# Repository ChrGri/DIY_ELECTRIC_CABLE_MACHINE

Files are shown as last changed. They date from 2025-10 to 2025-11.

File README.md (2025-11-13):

# ESP32-Powered DIY Smart Cable Machine

An open-source, smart digital resistance machine using an ESP32, a high-torque StepperOnline A6 servo, and 3D-printed components. 

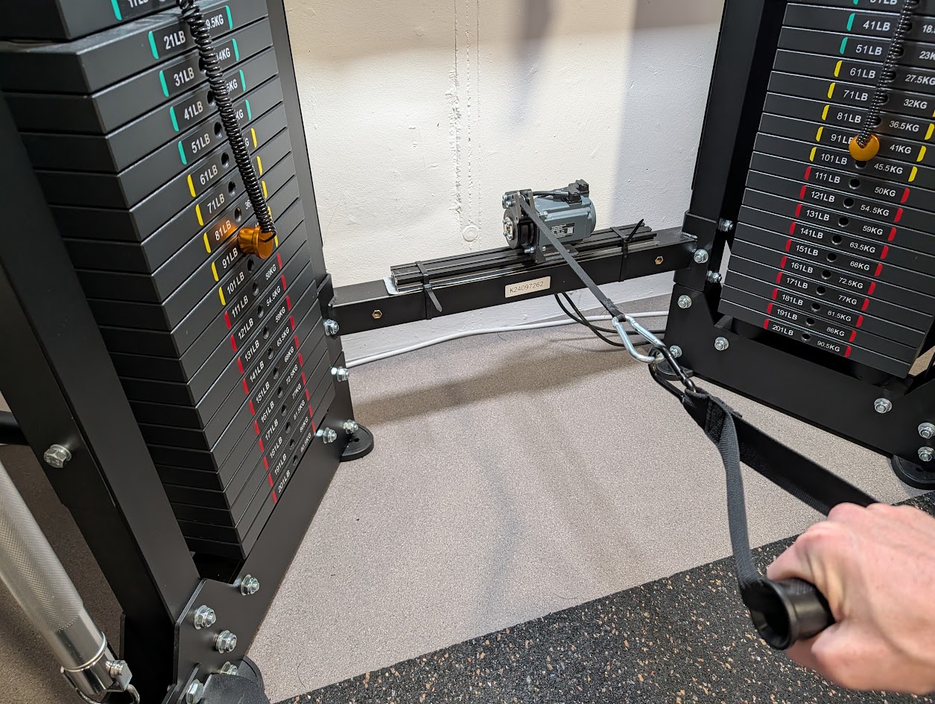
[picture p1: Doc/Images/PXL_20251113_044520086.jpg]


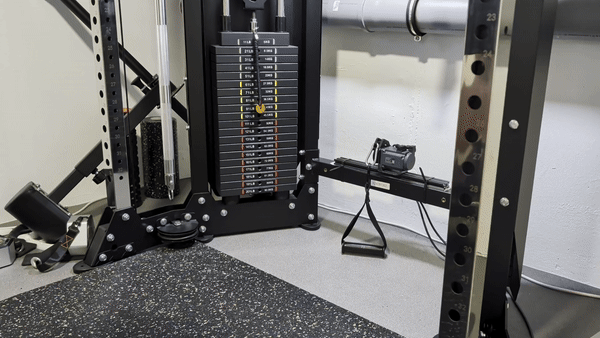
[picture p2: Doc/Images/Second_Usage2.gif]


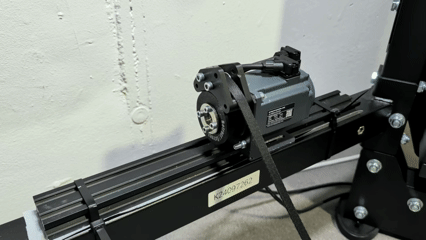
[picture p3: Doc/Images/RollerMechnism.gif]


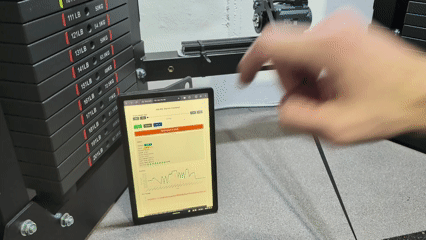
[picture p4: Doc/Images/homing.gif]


Action video, see [here](Doc/Videos/ActionVideo_1.mp4) and [here](Doc/Videos/ActionVideo_2.mp4).

The machine can be parameterized via web interface see <br>


# 🏋️ About The Project

This project is a Do-It-Yourself (DIY) approach to modern smart gyms. Instead of using a traditional weight stack, this machine uses a powerful closed-loop servo motor (StepperOnline A6) controlled by an ESP32 to provide resistance. This allows for digitally adjustable weight, smooth operation, and the potential for advanced features like eccentric-only training, custom resistance curves, and workout tracking.

The core of the build relies on accessible components: the powerful ESP32, a reliable industrial servo, a standard gym cable/handle, and custom 3D-printed parts for the spool and mounting. The ESP32 S3 was selected, since it has onboard WiFi and Bluetooth functionality and sufficient compute to allow web based control.  

## ✨ Key Features

- Digitally Adjustable Resistance: Change your "weight" from a web interface or physical buttons.
- High-Torque Servo: The StepperOnline A6 servo provides strong, smooth, and precise resistance.
- ESP32 Controller: Wi-Fi and Bluetooth-ready for a new UI, mobile app control, and OTA (Over-The-Air) updates.
- Fully Open-Source: All 3D models (STL/STEP) and firmware code are provided.
- Cost-Effective: Built for a fraction of the cost of commercial smart gyms.
- Customizable: Modify the code to add new modes (eccentric, isometric, chains) or integrate with other fitness apps.
- controller via web interface --> <br>
 <br>
- maximum force 12kg with the small A6 1.27Nm servo in direct drive, so no gearing. The larger 3.18 Nm might be able to provide 30 kg. 

# Support the team
I :heart: doing research. New hardware (e.g. servos, periphery, PCBs) is very expensive. Feel free to support me and thus fasten up the research activity.

Dev | captainchris |
--- | --- |
Buy me a coffee |  | 
Ko-fi |  |

## 🛠️ Bill of Materials (BOM)

Core Components
| Component | Model / Spec | Notes | (affiliate) link|
|--|--|--|--|
| Microcontroller | ESP32 S3 dev board |  | [Amazon](https://amzn.to/48NTnuW) |
| RJ45  cable |  | | [Amazon](https://amzn.to/47rE3Si) |
| TTL to Modbus converter |  |  | [Amazon](https://amzn.to/4nr72vo) |
| Servo Motor | StepperOnline A6 Servo | | [A6 1,27Nm](https://www.omc-stepperonline.com/de/a6-serie-400w-rs485-ac-servomotor-kit-3000rpm-1-27nm-17-bit-absolutwertgeber-ip67-a6-rs400h2a1-m17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) or [A6 3,18Nm](https://www.omc-stepperonline.com/de/a6-serie-1000w-rs485-ac-servomotor-kit-3000rpm-3-18nm-17-bit-absolutwertgeber-ip67-a6-rs1000h2a1-m17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)|
| Gym Cable | 3mm Polyster cord x 30m | Polyster cord is strong. | [Polyster cord](https://amzn.to/49fXEY2) |
| Handle | Standard D-Handle | Any cable machine attachment works. |  |

### Custom PCB
In the making.

### 3D Printed Parts

- Main Spool (attaches to servo shaft)
- Motor Mount
- ESP32 Enclosure

(All .stl and .step files are available in the /3D-Models directory of this repository)

## 🔌 Wiring Diagram

Here is the basic wiring schematic for connecting the ESP32 to the servo driver.

Warning: You are working with high-voltage AC (for the PSU) and high-current DC (for the servo). Always double-check your connections and ensure everything is unplugged when wiring.

### Connect the ESP32 to the TTL-to-Modbus board
   
| from ESP32 <br>  | TTL-to-Modbus Adapter <br>  |
|--|--|
| 3V3 | VCC |
| GPIO 4 (TX) | TXD |
| GPIO 6 (RX)  | RXD | 
| GND | GND |

### Connect the TTL-to-Modbus board to the RJ45 plug
| TTL-RJ45 Adapter <br>  | RJ45 <br>  |
|--|--|
| A+  | Pin 4 | 
| B- | Pin 5 |
| GND | Pin 8 |

 <br>
For Modbus communication and wiring please refer to this https://help.stepperonline.com/en/article/a6-servo-motor-rs485-operation-instruction-1u47bbl/

In the end, the wiring should look like this <br>
.

### Connect the RJ45 plug into the A6 servos CN3 port. 
Connect the RJ45 plug to CN3 port of the servo, port (5) in the image below:<br> 


### AC and Servo wiring
Please refer to the A6 manual for wiring of the A6 servo. As an example, here is how mine is wired up: <br>


## 💾 Firmware Setup

The firmware is written using the Arduino framework for the ESP32.
### VSCode
Install [VSCode](https://code.visualstudio.com/)

### PlatformIO
Install [PlatformIO](https://platformio.org/install/ide?install=vscode) in Visual Studio Code

> ![Note]
> When you restart VS Code for the first time after the PlatformIO extension is installed, it will install and build the development environment which will take a moment. Wait until it is complete before attempting to open the project.

### Flashing the firmware

1. IDE: Open [Code/Esp32S3](https://github.com/ChrGri/DIY_ELECTRIC_CABLE_MACHINE/tree/main/Code/Esp32S3) folder in VSCode
2. Flash: Build and upload the firmware to your ESP32.

## 🚀 How to Use

1. Power On: Connect the power supply and turn on the system.
2. Connect: The ESP32 will create a Wi-Fi network (or join yours, based on your config). Connect to its IP address from your phone or computer.
3. Web Interface: You will see a simple web page.
4. Set Weight: Enter your desired resistance (in kg or lbs) and press "Set".
5. Work Out! The servo will engage and provide resistance as you pull the handle.

## 📈 To-Do / Future Plans

[ ] Read servo alarms

[ ] Add eccentric resistance mode (higher resistance on release).

[ ] Workout tracking and history.

[ ] Add physical buttons/encoder to set weight without a phone.

## 🤝 Contributing

Pull requests are welcome! If you have ideas for improvements, new features, or bug fixes, please open an issue first to discuss what you would like to change.

1. Fork the Project
2. Create your Feature Branch (git checkout -b feature/AmazingFeature)
3. Commit your Changes (git commit -m 'Add some AmazingFeature')
4. Push to the Branch (git push origin feature/AmazingFeature)
5. Open a Pull Request

## ⚠️ Safety Disclaimer ⚠️

Build and use this device at your own risk.

This is an advanced DIY project that involves:

- High-Voltage AC: You will be working with mains AC voltage for the power supply, which carries a risk of severe electric shock or death.
- Powerful Motor: The A6 servo motor is extremely powerful. It can cause serious injury if hands, hair, or clothing get caught in the spool or cable.
- High Tension: The machine operates under high tension. Failure of 3D-printed parts, the cable, or mountings can result in a sudden release of load, posing a significant risk of injury.

The author(s) and contributors to this project assume no responsibility or liability for any injuries, damages, or losses resulting from the construction or use of this device. You are solely responsible for ensuring the safety of your build, performing all necessary safety checks, and using the machine in a safe manner.

## 📄 License
This project is licensed under the Creative Commons Attribution-NonCommercial-ShareAlike 4.0 International (CC BY-NC-SA 4.0). See the LICENSE file for details.

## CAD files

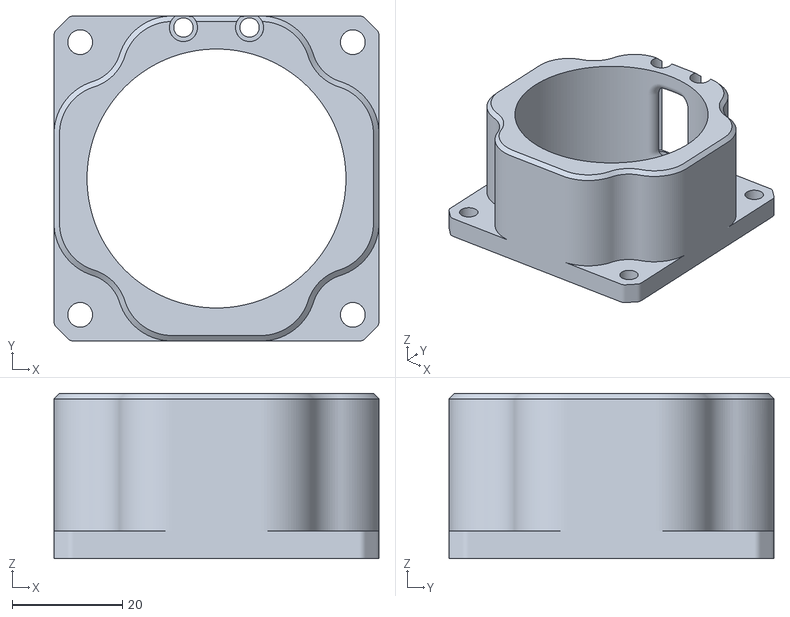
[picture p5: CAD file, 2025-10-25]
Cad/Stl/Housing.stl
59.0 x 59.0 x 30.0

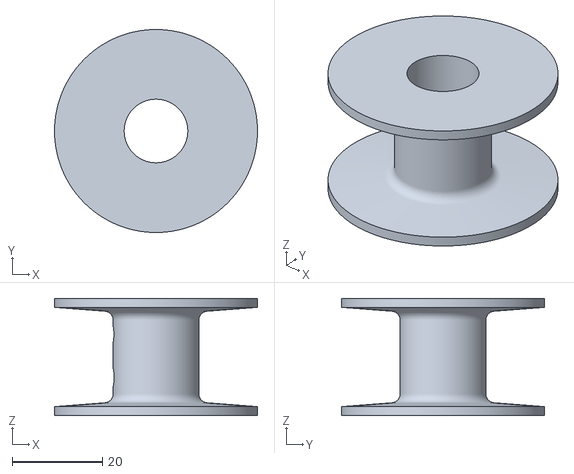
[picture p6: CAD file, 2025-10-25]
Cad/Stl/Roller.stl
45.0 x 45.0 x 26.0

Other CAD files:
Cad/F3d/A6ServoResistanceMachine v8.f3d

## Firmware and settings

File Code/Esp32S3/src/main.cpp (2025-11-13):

/*
 * Modbus Servo Control via Web Interface - ESP32-S3
 *
 * Implements a simple WiFi Manager, Modbus control, WebSocket interface,
 * and sends log messages/status data to the web browser via WebSocket.
 * Includes three live charts (Position/Time, Voltage/Time, Speed/Time) using Chart.js.
 *
 * *** MODIFIED ***
 * - Changed slider to represent and control Target Weight (kg) instead of Max Torque (%).
 * - Calculated conversion factor based on provided servo specs.
 * - Added third chart for Speed (rpm).
 */

#include <WiFi.h>
#include "esp_wifi.h"
#include <ESPAsyncWebServer.h>
#include <AsyncTCP.h>
#include <ModbusMaster.h>
#include <HardwareSerial.h>
#include <ArduinoJson.h>
#include <Preferences.h>

// --- Pin Definitions (ESP32-S3) ---
#define RXD2_PIN 6 // Modbus Serial2 RX
#define TXD2_PIN 4 // Modbus Serial2 TX

// --- WiFi Configuration ---
Preferences preferences;
String savedSSID = "";
String savedPassword = "";
const char *apSSID = "ServoSetup";

// --- Modbus Configuration ---
#define SERVO_DRIVE_SLAVE_ID 1
ModbusMaster node;
HardwareSerial ModbusSerial(2);

// --- Modbus Register Addresses (Hex) ---
#define REG_CONTROL_MODE 0x0000        // C00.00
#define REG_TARGET_SPEED 0x0321        // C03.21
#define REG_TORQUE_REF_SRC 0x0340      // C03.40
#define REG_TARGET_TORQUE 0x0341       // C03.41
#define REG_MODBUS_SERVO_ON 0x0411     // Servo Enable/Disable (Write)
#define REG_DI5_FUNCTION 0x0410        // C04.10
#define REG_SOFT_LIMIT_ENABLE 0x0607   // C06.07 (1=Enable +/- Limits)
#define REG_SOFT_LIMIT_NEG 0x0608      // C06.08 (32-bit Negative Limit) - Alias for clarity
#define REG_C06_08 REG_SOFT_LIMIT_NEG  // Keep old name for compatibility
#define REG_OUT_OF_CONTROL_PROT 0x0620 // C06.20 (Out of Control Protection Mode)
#define REG_SPEED_FEEDBACK 0x4001      // U40.01
#define REG_TORQUE_FEEDBACK 0x4003     // U40.03
#define REG_DI_STATUS 0x04004          // C040.04
#define REG_BUS_VOLTAGE 0x4006         // U40.06
#define REG_RMS_CURRENT 0x400C         // U40.0C
#define REG_POSITION_FEEDBACK_L 0x4016 // U40.16 (Low)
#define REG_POSITION_FEEDBACK_H 0x4017 // U40.16 (High)
#define REG_TEMP_IGBT 0x4030           // U40.30 (IGBT Temperature in 0.1 C)
#define REG_TEMP_MOTOR 0x4031          // U40.31 (Motor Temperature in 0.1 C)
#define REG_SERVO_STATUS 0x410A        // U41.0A

// --- Webserver & WebSocket ---
AsyncWebServer server(80);
AsyncWebSocket ws("/ws");
StaticJsonDocument<350> wsJsonTx; // Slightly increased size for temp values
StaticJsonDocument<128> wsJsonRx;
#define MAX_LOG_MSG_LENGTH 150

// --- Global State Variables ---
bool servoIsEnabledTarget = false;
bool servoIsEnabledActual = false;
bool modbusOk = false;
int16_t currentTargetTorque = 0; // Represents the MAX torque (0-2000) sent to servo
int16_t actualSpeed = 0;
int16_t actualTorque = 0;
uint16_t busVoltage = 0;
int16_t rmsCurrent = 0;
int32_t actualPosition = 0;
int16_t igbtTemp = 0;
int16_t motorTemp = 0;
uint16_t actualServoStatus = 0;
uint16_t diStatus = 0;
int modbusConsecutiveErrors = 0; // Counter for Modbus errors
const int MAX_MODBUS_ERRORS = 5; // Number of errors before connection is considered bad
bool enableCmdSent = false;      // Track if enable command was sent

// --- Homing State ---
enum HomingState {
    HOMING_IDLE,
    HOMING_START,
    HOMING_WAIT_FOR_RUNNING,
    HOMING_MOVING_SLOW,
    HOMING_DONE
};
volatile HomingState homingState = HOMING_IDLE;
int32_t homingPosition = 0; // Loaded from Preferences or set by Homing
const int16_t HOMING_SPEED_RPM = 120; // Homing speed 120 RPM
const int16_t HOMING_TORQUE_THRESHOLD = 200; // 20.0% Torque (as "current" threshold)

// Timer variables for Homing
unsigned long homingStartTime = 0;
const long HOMING_START_TIMEOUT = 2000; // 2 seconds wait for "Running"

// Timing control
unsigned long lastModbusReadTime = 0;
unsigned long lastModbusCheckTime = 0;
unsigned long lastWsSendTime = 0;
const long modbusReadInterval = 50;
const long modbusCheckInterval = 2000;
const long wsSendInterval = 100;
unsigned long wifiReconnectTimer = 0;

// Flag if we are in AP mode
bool isInAPMode = false;

// --- Helper function for logging ---
void logToBrowser(const char* format, ...) {
    char msgBuffer[MAX_LOG_MSG_LENGTH];
    va_list args;
    va_start(args, format);
    vsnprintf(msgBuffer, sizeof(msgBuffer), format, args);
    va_end(args);
    Serial.println(msgBuffer); // Always to Serial
    if (!isInAPMode && ws.count() > 0 && WiFi.status() == WL_CONNECTED) {
        bool likely_in_ws_callback = false; // Simplified assumption
        if (!likely_in_ws_callback) {
             wsJsonTx.clear(); wsJsonTx["type"] = "log"; wsJsonTx["message"] = msgBuffer;
             String jsonString; serializeJson(wsJsonTx, jsonString); ws.textAll(jsonString);
        }
    }
}

// --- HTML for main page (*** UPDATED: Slider controls weight (kg) ***) ---
const char index_html[] PROGMEM = R"rawliteral(
<!DOCTYPE HTML><html>
<head>
  <title>ESP32 Servo Control</title>
  <meta name="viewport" content="width=device-width, initial-scale=1">
  <script src="https://cdn.jsdelivr.net/npm/chart.js"></script>
  <script src="https://cdn.jsdelivr.net/npm/moment@^2"></script>
  <script src="https://cdn.jsdelivr.net/npm/chartjs-adapter-moment@^1"></script>

  <style>
    body { font-family: Arial, sans-serif; padding: 15px; background-color: #f4f4f4; }
    h2 { color: #333; text-align: center; }
    .container { max-width: 700px; margin: auto; background: #fff; padding: 20px; border-radius: 8px; box-shadow: 0 0 10px rgba(0,0,0,0.1); }
    .control-group { margin-bottom: 20px; }
    label { display: block; margin-bottom: 5px; font-weight: bold; }
    input[type=range] { width: 100%; }
    .value-display { font-size: 1.2em; color: #007bff; text-align: center; margin-top: 10px; }
    .btn { padding: 10px 15px; font-size: 1em; cursor: pointer; border: none; border-radius: 5px; margin-right: 10px; }
    .btn-enable { background-color: #28a745; color: white; }
    .btn-disable { background-color: #dc3545; color: white; }
    .btn-home { background-color: #007bff; color: white; }
    .btn-disabled { background-color: #6c757d; color: white; cursor: not-allowed;}
    .btn-estop { 
        background-color: #ff0000; color: white; font-weight: bold; width: 100%; 
        margin-top: 10px; padding: 15px; font-size: 1.2em; margin-right: 0;
    }
    .status { margin-top: 20px; padding: 15px; background-color: #e9ecef; border-radius: 5px; }
    .status p { margin: 5px 0; }
    .status strong { color: #555; }
    .status-badge { padding: 3px 8px; border-radius: 4px; color: white; font-weight: bold; display: inline-block; min-width: 60px; text-align: center;}
    .status-run { background-color: #28a745; }
    .status-ready { background-color: #ffc107; color: #333;}
    .status-nr { background-color: #6c757d; }
    .status-fault { background-color: #dc3545; }
    .status-off { background-color: #6c757d; }
    .status-modbus-ok { background-color: #17a2b8; }
    .status-modbus-fail { background-color: #ffc107; color: #333; }
    .di-indicator { display: inline-block; width: 15px; height: 15px; border-radius: 50%; margin-left: 5px; vertical-align: middle;}
    .di-on { background-color: limegreen; }
    .di-off { background-color: lightgrey; }
    #logOutput { width: 98%; height: 150px; background-color: #333; color: #fff; font-family: monospace; font-size: 0.8em; border: 1px solid #ccc; border-radius: 4px; margin-top: 15px; overflow-y: scroll; padding: 5px; }
    .chart-container { margin-top: 30px; height: 250px; } 

    /* --- NEW STYLES --- */
    .slider-wrapper { display: flex; align-items: center; gap: 8px; margin-top: 5px; }
    .slider-wrapper input[type=range] { flex: 1; margin: 0; } /* Let it grow, remove default margins */
    .btn-inc { 
      background-color: #6c757d; /* Grey */
      color: white; 
      width: 60px; /* Fixed width */
      flex-shrink: 0; /* Don't shrink */
      margin: 0; /* Override .btn margin */
      padding: 8px 10px; /* Adjust padding */
      font-size: 0.9em;
    }
    /* --- END NEW STYLES --- */

  </style>
</head>
<body>
  <div class="container">
    <h2>A6-RS Servo Control</h2>
    
    <div class="control-group">
      <label for="weightSlider">Target Weight (kg):</label> 
      <div class="slider-wrapper"> <button id="minus5Btn" class="btn btn-inc">-5kg</button>
        <button id="minus1Btn" class="btn btn-inc">-1kg</button>
        <input type="range" id="weightSlider" min="0" max="120" value="0" step="1"> <button id="plus1Btn" class="btn btn-inc">+1kg</button>
        <button id="plus5Btn" class="btn btn-inc">+5kg</button>
      </div>
      <div id="weightValue" class="value-display">0.0 kg</div>
    </div>
    <div class="control-group">
      <button id="enableBtn" class="btn btn-enable">Enable</button>
      <button id="disableBtn" class="btn btn-disable">Disable</button>
      <button id="homeBtn" class="btn btn-home">Homing</button>
    </div>
    <div class="control-group">
        <button id="estopBtn" class="btn btn-estop">EMERGENCY STOP</button>
    </div>
    <div class="status">
      <h4>Status</h4>
      <p>Modbus: <span id="modbusStatus" class="status-badge status-modbus-fail">Checking...</span></p>
      <p>Servo: <span id="servoStatus" class="status-badge status-off">Unknown</span> (<span id="servoStatusCode">?</span>)</p>
      <p>Position: <strong id="actualPosition">0</strong></p>
      <p>Speed: <strong id="actualSpeed">0</strong> rpm</p>
      <p>Actual Torque: <strong id="actualTorque">0.0</strong> %</p>
      <p>Current: <strong id="rmsCurrent">0.0</strong> A</p>
      <p>Bus Voltage: <strong id="busVoltage">0.0</strong> V</p>
      <p>IGBT Temp: <strong id="igbtTemp">0.0</strong> &deg;C</p>
      <p>Motor Temp: <strong id="motorTemp">0.0</strong> &deg;C</p>
      <p>DIs (1-8):
          <span id="di1" class="di-indicator di-off"></span> <span id="di2" class="di-indicator di-off"></span>
          <span id="di3" class="di-indicator di-off"></span> <span id="di4" class="di-indicator di-off"></span>
          <span id="di5" class="di-indicator di-off"></span> <span id="di6" class="di-indicator di-off"></span>
          <span id="di7" class="di-indicator di-off"></span> <span id="di8" class="di-indicator di-off"></span>
          (<span id="diValueHex">0x00</span>)
      </p>
    </div>

      <div class="chart-container">
        <h4>Position</h4>
        <canvas id="posChart"></canvas>
      </div>
       <div class="chart-container">
        <h4>Bus Voltage</h4>
        <canvas id="voltChart"></canvas>
      </div>
       
      <div class="chart-container">
        <h4>Geschwindigkeit</h4>
        <canvas id="spdChart"></canvas>
      </div>
      <textarea id="logOutput" readonly></textarea>
  </div>
<script>
  var gateway = `ws://${window.location.hostname}/ws`;
  var websocket;
  var servoTargetState = false; 
  var logTextArea = null;
  const MAX_LOG_LINES = 100;

  // Chart Variables
  var posChart = null;
  var voltChart = null;
  var spdChart = null; // --- NEU ---
  var commonLabels = []; 
  var posChartData = { labels: commonLabels, datasets: [{ label: 'Position (Steps)', data: [], borderColor: 'rgb(75, 192, 192)', backgroundColor: 'rgba(75, 192, 192, 0.5)', tension: 0.1 }] };
  var voltChartData = { labels: commonLabels, datasets: [{ label: 'Bus Voltage (V)', data: [], borderColor: 'rgb(255, 99, 132)', backgroundColor: 'rgba(255, 99, 132, 0.5)', tension: 0.1 }] };
  // --- NEU ---
  var spdChartData = { labels: commonLabels, datasets: [{ label: 'Geschwindigkeit (rpm)', data: [], borderColor: 'rgb(54, 162, 235)', backgroundColor: 'rgba(54, 162, 235, 0.5)', tension: 0.1 }] };
  // --- ENDE NEU ---
  const TIME_WINDOW_MS = 20000; // 20 seconds

  // *** NEW: Conversion factor ***
  const KG_TO_MODBUS_FACTOR = 169.8; // Approx (9.81 * 0.022 / 1.27) * 100 * 10

  window.addEventListener('load', onLoad);

  function onLoad(event) {
    logTextArea = document.getElementById('logOutput');
    initWebSocket();
    initUI();
    initCharts(); 
  }

  function initUI() {
    document.getElementById('weightSlider').addEventListener('input', onSliderInput); // Changed ID
    document.getElementById('weightSlider').addEventListener('change', onSliderChange); // Changed ID
    
    // *** NEW BUTTON LISTENERS ***
    document.getElementById('minus5Btn').addEventListener('click', onMinus5Click);
    document.getElementById('minus1Btn').addEventListener('click', onMinus1Click);
    document.getElementById('plus1Btn').addEventListener('click', onPlus1Click);
    document.getElementById('plus5Btn').addEventListener('click', onPlus5Click);
    // *** END NEW LISTENERS ***

    document.getElementById('enableBtn').addEventListener('click', onEnableClick);
    document.getElementById('disableBtn').addEventListener('click', onDisableClick);
    document.getElementById('homeBtn').addEventListener('click', onHomeClick);
    document.getElementById('estopBtn').addEventListener('click', onEstopClick); 
    updateButtonStates(false, false); 
  }

  // Initializes Charts
  function initCharts() {
    const posCtx = document.getElementById('posChart').getContext('2d');
    posChart = new Chart(posCtx, {
        type: 'line', data: posChartData, options: { responsive: true, maintainAspectRatio: false, animation: false, scales: { x: { type: 'time', time: { unit: 'second', tooltipFormat: 'HH:mm:ss', displayFormats: { second: 'HH:mm:ss' } }, title: { display: true, text: 'Time' } }, y: { title: { display: true, text: 'Position (Steps)' } } }, plugins: { legend: { display: false }, title: { display: false } } }
    });
    const voltCtx = document.getElementById('voltChart').getContext('2d');
    voltChart = new Chart(voltCtx, {
        type: 'line', data: voltChartData, options: { responsive: true, maintainAspectRatio: false, animation: false, scales: { x: { type: 'time', time: { unit: 'second', tooltipFormat: 'HH:mm:ss', displayFormats: { second: 'HH:mm:ss' } }, title: { display: true, text: 'Time' } }, y: { title: { display: true, text: 'Bus Voltage (V)' }, suggestedMin: 0, suggestedMax: 400 } }, plugins: { legend: { display: false }, title: { display: false } } }
    });
    
    // --- NEU --- Initialisierung für Speed Chart
    const spdCtx = document.getElementById('spdChart').getContext('2d');
    spdChart = new Chart(spdCtx, {
        type: 'line', data: spdChartData, options: { responsive: true, maintainAspectRatio: false, animation: false, scales: { x: { type: 'time', time: { unit: 'second', tooltipFormat: 'HH:mm:ss', displayFormats: { second: 'HH:mm:ss' } }, title: { display: true, text: 'Time' } }, y: { title: { display: true, text: 'Geschwindigkeit (rpm)' } } }, plugins: { legend: { display: false }, title: { display: false } } }
    });
    // --- ENDE NEU ---
  }

  // --- MODIFIZIERT --- Adds data to ALL charts and enforces time window
  function addDataToCharts(timestamp, position, voltage, speed) {
    if (!posChart || !voltChart || !spdChart) return; // spdChart-Check hinzugefügt
    commonLabels.push(timestamp);
    posChartData.datasets[0].data.push(position); 
    voltChartData.datasets[0].data.push(voltage);
    spdChartData.datasets[0].data.push(speed); // NEU
    
    const now = Date.now();
    while (commonLabels.length > 0 && (now - commonLabels[0] > TIME_WINDOW_MS)) {
        commonLabels.shift(); 
        posChartData.datasets[0].data.shift(); 
        voltChartData.datasets[0].data.shift(); 
        spdChartData.datasets[0].data.shift(); // NEU
    }
    posChart.update('none'); 
    voltChart.update('none'); 
    spdChart.update('none'); // NEU
  }

  function initWebSocket() {
    console.log('Trying to open a WebSocket connection...');
    websocket = new WebSocket(gateway);
    websocket.onopen    = onOpen;
    websocket.onclose   = onClose;
    websocket.onmessage = onMessage;
  }

  function logToConsole(message) {
      if (!logTextArea) return;
      const now = new Date();
      const timeString = now.toTimeString().split(' ')[0]; 
      logTextArea.value += timeString + ': ' + message + '\n';
      let lines = logTextArea.value.split('\n');
      if (lines.length > MAX_LOG_LINES) {
          logTextArea.value = lines.slice(lines.length - MAX_LOG_LINES).join('\n');
      }
      logTextArea.scrollTop = logTextArea.scrollHeight; 
  }

  function onOpen(event) {
    console.log('Connection opened');
    logToConsole('WebSocket Connection Opened');
    document.getElementById('modbusStatus').textContent = 'ESP Connected';
    document.getElementById('modbusStatus').className = 'status-badge status-modbus-ok';
    websocket.send(JSON.stringify({command: "getStatus"}));
  }

  function onClose(event) {
    console.log('Connection closed');
    logToConsole('WebSocket Connection Closed');
    document.getElementById('modbusStatus').textContent = 'ESP Disconnected';
    document.getElementById('modbusStatus').className = 'status-badge status-modbus-fail';
    document.getElementById('servoStatus').textContent = 'Unknown';
    document.getElementById('servoStatus').className = 'status-badge status-modbus-fail';
    setTimeout(initWebSocket, 2000);
  }

  function onMessage(event) {
    try {
      var data = JSON.parse(event.data);

      if (data.type === 'log') {
        logToConsole(data.message);
        return;
      }
      
      if (data.type === 'homingStatus') {
        logToConsole('Homing Status: ' + data.message);
        if (data.status === 'finished' || data.status === 'failed') {
            document.getElementById('homeBtn').disabled = false;
            document.getElementById('homeBtn').classList.remove('btn-disabled');
        }
        return;
      }

      if (data.type === 'status') {
        // Update status indicators (as before)
        document.getElementById('actualPosition').textContent = data.pos;
        document.getElementById('actualSpeed').textContent = data.spd;
        document.getElementById('actualTorque').textContent = (data.trq / 10.0).toFixed(1);
        document.getElementById('rmsCurrent').textContent = (data.cur / 10.0).toFixed(1);
        document.getElementById('busVoltage').textContent = (data.vbus / 10.0).toFixed(1);
        document.getElementById('igbtTemp').textContent = (data.igbtTemp / 10.0).toFixed(1); 
        document.getElementById('motorTemp').textContent = (data.motorTemp / 10.0).toFixed(1); 

        document.getElementById('modbusStatus').textContent = data.modbusOk ? 'OK' : 'FAIL';
        document.getElementById('modbusStatus').className = data.modbusOk ? 'status-badge status-modbus-ok' : 'status-badge status-modbus-fail';

        let statusText = 'Unknown'; let statusClass = 'status-badge status-nr';
        switch(data.servoStatus) {
            case 0: statusText = 'Not Ready'; statusClass = 'status-badge status-nr'; break;
            case 1: statusText = 'Ready'; statusClass = 'status-badge status-ready'; break;
            case 2: statusText = 'Running'; statusClass = 'status-badge status-run'; break;
            case 3: statusText = 'Fault'; statusClass = 'status-badge status-fault'; break;
            default: statusText = 'Invalid (' + data.servoStatus + ')'; statusClass = 'status-badge status-fault'; break;
        }
        document.getElementById('servoStatus').textContent = statusText;
        document.getElementById('servoStatus').className = statusClass;
        document.getElementById('servoStatusCode').textContent = data.servoStatus;

        let isActuallyEnabled = (data.servoStatus === 2);
        let homingInProgress = data.homingInProgress || false;
        updateButtonStates(isActuallyEnabled, homingInProgress);

        let diVal = data.diStatus;
        document.getElementById('diValueHex').textContent = '0x' + diVal.toString(16).padStart(4, '0'); // Padded to 4 for 0xFFFF
        for (let i = 1; i <= 8; i++) {
            let indicator = document.getElementById('di' + i);
            indicator.className = ((diVal >> (i - 1)) & 1) ? 'di-indicator di-on' : 'di-indicator di-off';
        }

        // --- MODIFIZIERT --- Update charts with new data, including speed
        addDataToCharts(Date.now(), data.pos, data.vbus / 10.0, data.spd);

      }
    } catch (e) {
      console.error('Error parsing JSON:', e, 'Data:', event.data);
      logToConsole('Error processing WebSocket message: ' + event.data);
    }
  }

  // *** REFACTORED Slider/Button functions ***

  // onSliderInput: Update UI only, don't send command (prevents flooding)
  function onSliderInput(event) {
    updateWeight(event.target.value, false); 
  }
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
void loop() {
    if (isInAPMode) {
        delay(10); // AP Mode does very little in loop
    } else if (WiFi.status() == WL_CONNECTED) {
        appLoop(); // Run main application logic
        wifiReconnectTimer = 0; // Reset reconnect timer if connected
    } else {
        // STA Mode but connection lost
        if(wifiReconnectTimer == 0) {
            logToBrowser("WiFi connection lost. Attempting to reconnect...");
            wifiReconnectTimer = millis();
        }
        if (millis() - wifiReconnectTimer > 10000) {
             Serial.print(".");
             WiFi.disconnect(); // Explicitly disconnect before reconnect
             WiFi.reconnect();
             wifiReconnectTimer = millis();
        }
        // Ensure Modbus/Servo is off during disconnect
        if (modbusOk || servoIsEnabledActual) {
            disableServoModbus(); // Try to send disable command
            modbusOk = false;
            actualServoStatus = 0;
            servoIsEnabledActual = false;
            servoIsEnabledTarget = false;
            enableCmdSent = false; // Reset flag on disconnect
            homingState = HOMING_IDLE; // Abort homing on WiFi loss
            logToBrowser("WiFi lost, Modbus communication stopped.");
        }
        delay(500); // Wait between checks
    }
}

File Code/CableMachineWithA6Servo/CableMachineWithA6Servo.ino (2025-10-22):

// C03.40 = 1 AI1 analog reference


#include <driver/dac.h>

// --- New ---
// Define the ADC pin for the potentiometer
// GPIO 34 is a good choice as it's ADC1_CH6 and input-only
const int potPin = 34; 
// --- End New ---


// // Pins for LOLIN S2 Mini
// const int dacPin = 17; // DAC Channel 1 is GPIO17 on ESP32-S2
// const dac_channel_t dacChannel = DAC_CHANNEL_1; // Use DAC_CHANNEL_1 enum

const int dacPin = 25; // DAC Channel 1 is GPIO25 on standard ESP32
const dac_channel_t dacChannel = DAC_CHANNEL_1; // Use DAC_CHANNEL_1 enum

const int servoOnPin = 4; // Using GPIO4 for S-ON
#define PI_FL32         3.1415926535897932384626433832795f

void setup() {
  Serial.begin(115200);
  pinMode(servoOnPin, OUTPUT);
  digitalWrite(servoOnPin, HIGH); // Start with Servo OFF (S-ON inactive)

  // Configure DAC
  dac_output_enable(dacChannel);
  dac_output_voltage(dacChannel, 0); // Set initial torque reference to 0V (DAC value 0)

  // --- New ---
  // Set the potentiometer pin as an input
  pinMode(potPin, INPUT);
  Serial.println("ADC and DAC Setup Complete. Potentiometer connected to GPIO 34?");
  // --- End New ---

  delay(2000); // Wait a bit

  // --- Example: Enable Servo and command ~1V (approx 10% torque if 10V=100%) ---
  // Note: Your comment says "S-ON HIGH" but code sets it LOW to activate
  Serial.println("Enabling Servo (S-ON LOW)"); 
  digitalWrite(servoOnPin, LOW); // Activate S-ON
  delay(500); // Allow time for drive to enable
}

void loop() {

  // --- Replaced Sine Wave Calculation ---
  // long timeNowMillis = millis();
  // float seconds_fl32 = timeNowMillis / 1000.0f;
  // float f_Hz_fl32 = 0.2f;

  // float amplitude = 100.0f * fabsf( sinf( 2.0f * PI_FL32 * f_Hz_fl32 * seconds_fl32 ) );

  // amplitude = constrain(amplitude, 0.0f, 255.0f);



  // 1. Read the potentiometer value. 
  // On ESP32, analogRead() returns a 12-bit value (0 to 4095)
  int potValue = analogRead(potPin);

  // 2. Map the 12-bit ADC range (0-4095) to the 8-bit DAC range (0-255)
  int dacValue = map(potValue, 0, 4095, 0, 255);
  
  // 3. Constrain the value just in case of ADC noise (optional but good practice)
  dacValue = constrain(dacValue, 0, 255);
  
  // --- End of Replaced Section ---


  // // --- Example: Enable Servo and command ~1V (approx 10% torque if 10V=100%) ---
  // Serial.println("Enabling Servo (S-ON HIGH)");
  // digitalWrite(servoOnPin, LOW); // Activate S-ON
  // delay(500); // Allow time for drive to enable

  // Calculate DAC value for desired voltage (approx 1V)
  // DAC is 8-bit (0-255), output is ~0V to 3.3V
  // int dacValue = (int)((1.0 / 3.3) * 255);
  
  // This value is now controlled by the potentiometer mapping above
  // int dacValue = (int)amplitude; 

  // --- Modified Serial Print ---
  Serial.print("Pot (ADC): ");
  Serial.print(potValue);
  Serial.print(" -> Setting DAC output: ");
  Serial.print(dacValue);
  Serial.println(")");
  // --- End Modified Serial Print ---

  dac_output_voltage(dacChannel, dacValue);

  delay(50); // Poll the potentiometer every 50ms

  // // --- Example: Ramp down torque and disable servo ---
  // Serial.println("Ramping down torque");
  // for (int val = dacValue; val >= 0; val--) {
  //   dac_output_voltage(dacChannel, val);
  //   delay(10);
  // }

  // Serial.println("Disabling Servo (S-ON LOW)");
  // digitalWrite(servoOnPin, HIGH); // Deactivate S-ON
  // delay(1000); // Wait

  // // --- Loop break or add other commands ---
  // while (true) { // Stop after one cycle for this example
  //    delay(1000);
  // }

  // error and alarm codes on page 213
}

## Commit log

2025-10-22 Added CAD files for A6 400W servo
    [A6ServoResistanceMachine v8.f3d, Housing.stl, Roller.stl]
2025-10-25 Added code to control the servo via ESP32 S3 and modbus
2025-10-25 ESP32 will open access point at first boot where user can insert wifi credentials
2025-10-25 Write register bugfix. Running version
    [main.cpp]
2025-10-25 Added homing function
2025-10-25 Added emergency button
2025-10-26 Limit homing by C06.07 and C06.08
2025-10-29 Show temperature. Refactoring. Faster communication.
2025-10-29 English version + plot position and voltage in webbrowser
2025-10-29 Slider in kg instead of torque
2025-11-08 Bugfix DI register address
    [main.cpp]
2025-11-08 Add weight increment buttons to user interface
